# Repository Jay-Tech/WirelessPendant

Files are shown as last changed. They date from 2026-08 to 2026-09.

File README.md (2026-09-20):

# Wireless Pendant

Firmware for a wireless handwheel pendant for a grblHAL machine, and for the
receiver board that carries it to the PC. The sender application it talks to is
a separate project — [Jay-Tech/GrblHAL-Sender](https://github.com/Jay-Tech/GrblHAL-Sender),
whose [Wireless Pendant](https://github.com/Jay-Tech/GrblHAL-Sender#wireless-pendant)
section covers the settings at that end. What crosses between them is
[the wire protocol](micropython/pendant/protocol.py) — newline-delimited JSON,
the same either way it travels.

Two boards, both **ESP32-S3**:

| | |
|---|---|
| **pendant** | the handheld — encoder wheel, touch screen, battery. Waveshare ESP32-S3-Touch-LCD-3.5 |
| **receiver** | plugs into the sender's PC, presents a serial port, talks ESP-NOW to the pendant |

The pendant reaches the sender two ways. Over **ESP-NOW** it talks to the
receiver board, which needs no network and no credentials — this is the one it
is built around, because an open-source pendant cannot require the builder to
have usable WiFi in their shop. Over **WiFi** it joins the shop network and
opens a TCP session to the sender directly; that path stays because it is the
reference every jog constant was fitted against.

New board? → [Setting up a board](#setting-up-a-board). One command.

## The hardware

Three things, and none of them is a breadboard any more: an all-in-one host
board, a passive PCB that breaks its header out, and a printed enclosure. All of
it lives under [`hardware/`](hardware/).

| | | |
|---|---|---|
| **host board** | bought | [Waveshare ESP32-S3-Touch-LCD-3.5](https://www.waveshare.com/esp32-s3-touch-lcd-3.5.htm?sku=30733) — MCU, display, touch, PMIC and radio on one board |
| **PSB v1.0** | [`hardware/PendantPcb/`](hardware/PendantPcb/) | breaks that board's 32-pin header out to the handwheel and the three buttons. Carries no components at all |
| **enclosure** | [`hardware/CADandSTL/`](hardware/CADandSTL/) | Fusion 360 sources and printable STLs — the handheld, and a dock for it |

**The bill of materials is five orderable items, with no passives at all:** the
host board, an MPG handwheel, three tactile switches, a LiPo cell, and whatever
the printer eats. A 5 V boost module and the encoder's 22 kΩ divider pair were
both on that list until 2026-08-15 and were measured off it rather than reasoned
off it — [platform-decision.md](hardware/platform-decision.md) carries the
numbers, and [Encoder wiring](#encoder-wiring) below keeps the divider material
for the Pico build and for characterising an unknown wheel.

### The host board

[Waveshare ESP32-S3-Touch-LCD-3.5](https://www.waveshare.com/esp32-s3-touch-lcd-3.5.htm?sku=30733),
SKU 30733.

| | |
|---|---|
| MCU | ESP32-S3R8, dual Xtensa LX7 @ 240 MHz |
| Memory | 512 KB SRAM + **8 MB octal PSRAM**, 16 MB flash |
| Display | 3.5" IPS, 320 x 480, ST7796 over SPI |
| Touch | FT6336U, I²C `0x38`, polled |
| Power | **AXP2101** — charger, power path, fuel gauge and power button in one part, switching rather than linear |
| Battery | 3.7 V LiPo on an MX1.25 header, plus a separate SH1.0 header for an RTC cell |
| Radio | WiFi 4 (2.4 GHz) + BLE 5 on an onboard antenna, **with an IPEX pad for an external one** |
| Unused here | PCF85063 RTC, QMI8658 IMU, ES8311 codec, mic, speaker header, TF slot, camera header |
| Break-out | one 32-pin, 2.54 mm header — which is what PSB v1.0 mates to |

Two of those are why the board won. The **IPEX connector** — reached by
resoldering one resistor — is worth more on a handheld carried around a steel
machine than any latency figure measured here, and the Pico 2 W's antenna is
fixed. The **AXP2101** does in one part what the Pico build needed a LiPo Amigo
Pro and its wiring to do. The 8 MB PSRAM is enough for a full 320x480x2
framebuffer, which is also why the committed MicroPython build is the
`SPIRAM_OCT` variant rather than the plain one — see [ESP32-S3](#esp32-s3).

**The pin map is not in Waveshare's wiki and cannot be read off their schematic
PDF.** It came from their demo code, examples 08 and 11, which agree — and three
of the pins turn out not to be pins:

- **The LCD has no chip select.** The panel is permanently selected, so
  `st7796.py` has to tolerate `cs=None` rather than toggle something that does
  not exist.
- **LCD reset is an I²C write**, to a **TCA9554 expander at `0x20`** that is not
  in the board's advertised feature list and answers writes but not reads. The
  driver takes a reset *callable* instead of a pin, so the caller supplies either
  a pin toggle or an expander write and the driver stays portable.
- **Touch breaks out neither INT nor RST**, and needs neither, being polled.

Everything else transferred intact — the ST7796 init sequence, MADCTL, `INVON`,
the framebuffer push, and the whole of `screen.py` including the portrait layout,
the DRO digits, the step grid and the probe page. USB-C sits at the bottom edge,
which is where the reference pendant puts its cable, so the enclosure works with
it rather than against it.

An I²C scan of the board reads `0x18` ES8311, `0x20` TCA9554, `0x34` AXP2101,
`0x38` FT6336U, `0x51` PCF85063, `0x6b` QMI8658. That AXP2101 at `0x34` is also
how [`setup.py`](tools/setup.py) tells a pendant from a receiver, since the two
enumerate identically over USB — and it reads the chip ID rather than pinging the
address, so something else answering there is not mistaken for a battery.

> **The AXP2101's fuel gauge is not to be trusted on this board**, and the
> pendant does not use it. See [Battery and backlight](#battery-and-backlight)
> for what it did and what replaced it.

### PSB v1.0 — the breakout PCB

[`hardware/PendantPcb/`](hardware/PendantPcb/) is the KiCad project, with the fab
output in [`production/`](hardware/PendantPcb/production/).
[daughter-board.md](hardware/daughter-board.md) is the spec and the argument
behind it.

**It is built, and the pendant runs on it** — this is a board in service rather
than a drawing. The only difference between the fabricated boards and what is in
the repo is the silkscreen: they were made before the `PSB v1.0` version marking
was added, so they carry the functional labels and no revision. Nothing
electrical differs.

It exists because the host board brings almost everything out on that one
header, so a single mating board reaches every signal the pendant needs. The
alternative is seven flying leads soldered to a header, in a tool that gets
carried around a shop.

**Seven signals, and no components.** The move to a 3V3 encoder removed the last
two resistors it would have carried.

| Net | GPIO | J2 pin | Goes to |
|---|---|---|---|
| Encoder A | **9** | 14 | J3 pin 3 — direct, no resistor |
| Encoder B | **10** | 12 | J3 pin 4 — direct, no resistor |
| Encoder Vcc | — | 32 | J3 pin 1. **+3V3, measured 3.29 V — not 5 V, not VBAT** |
| Encoder 0V | — | 4, 30 | J3 pin 2 |
| `feed_hold` | **38** | 7 | SW1, silkscreened `HOLD` |
| `cycle_start` | **39** | 9 | SW2, silkscreened `START` |
| `zero_axis` | **40** | 11 | SW3, silkscreened `ZERO`, long hold |

The GPIO column was measured on the assembled handheld, 2026-08-16, and matches
`BUTTON_MAP` and `ENCODER_PIN_A/B` in
[`pendant.py`](micropython/pendant/pendant.py) — which is the authority. If
either moves, both have to. Buttons are active low against the S3's internal
pull-ups, with no external pull-ups and no debounce parts;
[`buttons.py`](micropython/pendant/buttons.py) debounces in software and has done
since the Pico build.

**Pin 32 is the one worth a meter.** The whole 3V3 encoder decision rests on it
being a regulated rail: the wheel is open-collector, so its outputs swing to
whatever supplies it, and they reach GP9 and GP10 with nothing in the way. On
VBAT or VBUS that is over the S3's ~3.6 V absolute maximum. 3.29 V says it is the
right rail.

**54.50 x 100.00 mm**, 2 mm chamfers on all four corners, and four drill groups —
which is the acceptance test, because anything outside the set is then visible at
a glance:

| Diameter | Plating | Count | |
|---|---|---|---|
| 0.300 | PTH | 2 | vias |
| 1.000 | PTH | 36 | 32 header + 4 encoder |
| 1.300 | PTH | 6 | three switches, two pads each |
| 2.200 | NPTH | 6 | mounting |

A missing 1.300 group means the switches were placed after the export — which
happened, and produced a zip with no buttons on it at all.

Two things on the board are deliberate traps, and both are cheap to check:

- **`+BATT` at J2 pin 1 is a single-node net** — that pad and nothing else on the
  board. Mate the boards and probe it: battery voltage means the numbering
  composes correctly through symbol, footprint and placement; 0 V or 3.3 V means
  one of those three mirrors did not cancel. Safe to probe precisely because
  nothing else is on it.
- **J3 has no keying**, and carries 3V3 and GND adjacent to each other. A cable
  fitted backwards puts reverse polarity across the wheel, so the `+ - A B`
  silkscreen and the pin 1 mark are load-bearing rather than decorative.

The three switches sit **19.0 mm apart, centred on the board's own centreline**.
The first layout had them at 19.5 and 18.5 with the middle one 0.5 mm off, and
unequal spacing between three caps is visible every time once the enclosure is
on.

A **reverse-polarity guard** for the battery is a second, smaller board. It shares
no net with PSB v1.0, which is why it is not on it, and
[daughter-board.md](hardware/daughter-board.md) has the circuit, what to buy, and
how to prove it before it meets the host board. Its KiCad project is gitignored,
so that specification is the only copy of it a clone gets.

### Printed parts

[`hardware/CADandSTL/`](hardware/CADandSTL/). Each folder holds one Fusion 360
file and the STLs exported from it — the `.f3d` is the source and the thing to
edit, the STLs are what a slicer wants. Sizes below are each mesh's measured
bounding box.

**The handheld** — [`Pendant/`](hardware/CADandSTL/Pendant/), from `Pendant.f3d`:

| File | Size, mm | |
|---|---|---|
| `Pendant.stl` | 70.00 x 27.65 x 186.00 | the body |
| `PcbCover.stl` | 54.70 x 3.16 x 100.00 | closes over PSB v1.0 — the footprint is that board's 54.50 x 100.00 plus clearance |
| `BatteryCover.stl` | 65.60 x 8.50 x 75.16 | the cell bay |
| `Button1.stl` | 10.80 x 10.64 x 8.80 | a cap for one of the three switches |
| `Button3.stl` | 10.80 x 10.64 x 8.80 | same envelope, different geometry |
| `ButtonUsbV2.stl` | 13.00 x 10.54 x 8.80 | the wider cap |
| `PowerButton.stl` | 8.39 x 3.60 x 4.60 | reaches the AXP2101's power button through the shell |

**The dock** — [`Mount/`](hardware/CADandSTL/Mount/), from `Mount.f3d`:

| File | Size, mm | |
|---|---|---|
| `Mount.stl` | 82.00 x 37.09 x 102.00 | the cradle the pendant sits in |
| `MountBase.stl` | 82.00 x 37.09 x 10.00 | its base, same footprint |
| `MountUsb.stl` | 20.00 x 20.00 x 5.90 | carries the USB-C end |
| `MountUsbLock.stl` | 11.70 x 6.10 x 17.70 | retains it |

**The body is 186 mm in its longest axis**, so it wants a bed with at least that
much in one direction — a 220 mm printer is fine, a 180 mm one is not.

**The button caps are one dimension chain, not three independent choices.** The
header fixes PSB v1.0's position relative to the host board in all three axes,
and the caps have to reach the enclosure top from there — so board stack height,
switch height and cap height are a single sum. The requirement the caps are cut
against is that each one **bottoms on the enclosure** at the end of its stroke
rather than on the switch, so the switch never takes the force of a gloved thumb,
and that the plunger is guided by a bore in the shell rather than by a spacer
resting on the board. [daughter-board.md](hardware/daughter-board.md) has the
reasoning; `Pendant.f3d` is where to check it.

## Why there is a Pico in here

The project started on a Raspberry Pi Pico 2 W, and that board is still on the
bench as `pico` — it is the reference the ESP32 gets compared against when
something feels wrong, which is why the notes below are kept rather than
deleted. Nothing shipping runs on it.

## Pico 2 W board notes

| | |
|---|---|
| MCU | RP2350, dual Cortex-M33 @ 150 MHz **or** dual Hazard3 RISC-V |
| RAM / flash | 520 KB SRAM / 4 MB QSPI |
| PIO | 3 blocks, 12 state machines |
| Radio | WiFi 4 (802.11n, 2.4 GHz) + Bluetooth 5.2 |
| Power | 1.8-5.5 V into VSYS via onboard buck-boost |

Three things that bite people on this specific board:

- **The onboard LED is not a GPIO.** It hangs off the CYW43 radio chip, so it's
  `Pin("LED")`, never `Pin(25)`. Most Pico tutorials assume a non-W board and
  will silently do nothing.
- **GP29 belongs to the WiFi SPI**, so the usable ADC channels are GP26/27/28
  (channels 0-2). Channel 4 is the internal temperature sensor.
- **Erratum RP2350-E9.** On the A2 stepping, an input pin can latch near 2.15 V
  instead of reading low, and the internal pull-downs are too weak to fix it.
  This hits PIO input programs too. Use an external pull-down of 8.2 kΩ or
  smaller. Stepping A4 corrects it — worth checking which one your board has
  before you spend an evening debugging a "broken" input.

## Setting up a board

```bash
python tools/setup.py
```

One command from a blank ESP32-S3 to a working pendant or receiver. It asks
what you are setting up, finds the board, flashes MicroPython if the board
needs it, checks the hardware matches the role, collects the WiFi and transport
settings, installs, restarts the board and reads back what it says on the way
up.

```bash
python tools/setup.py --pendant     # the handheld
python tools/setup.py --receiver    # the board at the sender's PC
python tools/setup.py --list        # what is attached, and what each one is
```

It replaces the two steps that used to be source edits: `BOARDS` in
[`tools/board.py`](tools/board.py) and a hand-filled `secrets.py`. **If you are
building this for the first time, this is the only thing you need to run** —
everything below is the manual equivalent, kept because it is what to fall back
on when a step misbehaves.

Two things worth knowing about how it finds boards:

- **It never opens a device it has not identified.** Only two USB descriptors
  are eligible — MicroPython on an S3 and on a Pico. Everything else is listed
  and skipped, and a grblHAL controller is named in that listing so you can see
  it was seen and left alone. This matters more than it sounds: `mpremote
  connect auto` once grabbed the STM32 controller on this bench and sent it
  raw-REPL bytes with a machine powered.
- **Each board records what it is**, in a `device.json` written at setup. That
  is what lets a board be found without an entry in `BOARDS`, and it is what
  `sync_board.py --receiver` now checks before it will write `receiver.py` over
  a `main.py` — the pendant and the receiver are both ESP32-S3 and enumerate
  identically, so before this the only guard was a name in a table that a new
  build had not filled in yet.

A pendant board is told apart from a receiver by the **AXP2101 power chip** at
I²C `0x34`, which the pendant carries and a bare receiver does not — and the
chip ID is read rather than the address pinged, so something else answering at
that address is not mistaken for a battery.

Set the receiver up on the sender's PC and it will offer to write the port into
the sender's own config. The sender still never scans for that port itself,
deliberately — see `PendantConfig` for why. This is not scanning; it just
flashed the board and knows where it is.

## Flashing MicroPython

The manual path, and the reference for what `setup.py` does.

### Pico 2 W

1. Download the Pico 2 W `.uf2` from
   [micropython.org/download/RPI_PICO2_W](https://micropython.org/download/RPI_PICO2_W/)
   — take whatever is current there rather than matching the S3 build committed
   at the root, since the two ports version independently. Make sure it's the
   `RPI_PICO2_W` build —
   the plain `RPI_PICO2` build has no WiFi and the plain `RPI_PICO_W` build is
   for the older RP2040 board.
2. Hold **BOOTSEL** while plugging in USB. The board mounts as a drive named
   `RP2350`.
3. Copy the `.uf2` onto it. The board reboots into MicroPython automatically.

If the board misbehaves after switching between Arm and RISC-V builds, or
between MicroPython and C SDK firmware, flash `flash_nuke.uf2` first to wipe
the flash, then reflash. Leftover filesystem blocks confuse the new firmware.

### ESP32-S3

Both the pendant and the receiver are ESP32-S3s, and neither takes a `.uf2` —
there is no BOOTSEL drive to drag a file onto, so flashing goes over the serial
port with `esptool`. The build this repo runs is committed at the root, and it
is the **`SPIRAM_OCT`** variant — these boards have octal SPIRAM, and the plain
`ESP32_GENERIC_S3` build leaves it unused. That mismatch does not fail at the
flash or at the boot; it surfaces much later as an allocation running out while
the pendant paints its display, which reads as a screen bug.

`setup.py` picks that variant on its own when both are sitting at the root, and
asks when it genuinely cannot tell — two versions of the same variant, say,
which is what a version bump leaves behind.

```bash
python -m pip install esptool
```

Put the board into its ROM bootloader: hold **BOOT**, tap **RESET**, release
**BOOT**. It re-enumerates as `303a:1001`, which `tools/board.py` labels
*"ROM bootloader — esptool, not mpremote"*. In MicroPython it is `303a:4001`
instead, and `esptool` will not talk to that one.

Then find the port it came up on — and look it up again rather than reusing what
it had a moment ago. The bootloader and MicroPython present different USB
descriptors, so Windows renumbers the board every time it is flashed. That is
also why every tool here targets a serial number instead of a COM port.

```bash
python -m esptool --chip esp32s3 --port COM# erase-flash
```

```bash
python -m esptool --chip esp32s3 --port COM# --baud 460800 write-flash -z 0 ESP32_GENERIC_S3-SPIRAM_OCT-<version>.bin
```

Offset `0`, not the `0x1000` the original ESP32 takes.

esptool 5 renamed these from `erase_flash` and `write_flash`; the underscore
forms still run but print a deprecation warning, which in the middle of a flash
reads like a fault. `setup.py` picks the spelling from the installed version.

Reset the board and it comes up in MicroPython with a new serial number. Every
S3 here enumerates identically, so that serial number is what distinguishes a
pendant from a receiver, and every tool resolves through it rather than through a
COM port.

There are two places it can come from. `setup.py` writes a `device.json` **on the
board**, which is what lets a board be recognised with no entry in any table —
prefer that. `BOARDS` in [`tools/board.py`](tools/board.py) is the older path and
still works; every id in it is this bench's, so all of them are wrong for you.
`python tools/board.py` lists what is attached and says so when the configured
board is not among them.

## Running the smoke test

Uses [`mpremote`](https://docs.micropython.org/en/latest/reference/mpremote.html):

```bash
pip install mpremote
```

Commands below invoke it as `python -m mpremote` rather than the bare
`mpremote`. On Windows with Microsoft Store Python, the `Scripts\` directory
holding `mpremote.exe` is not on `PATH`, so the bare command fails with
*"not recognized as the name of a cmdlet"* even though the install succeeded.
The `-m` form sidesteps that and works on every platform. See
[PATH fix](#windows-store-python-path) if you want the short command back.

> ### ⚠️ Do not use `connect auto` on a machine with a CNC controller attached
>
> `auto` connects to the first USB serial device it finds. If a grblHAL
> controller is plugged in, that can be the controller rather than the Pico —
> and mpremote will then send raw-REPL control bytes (`Ctrl-A`/`Ctrl-C`) to
> your machine controller trying to get a Python prompt. It happened here: the
> STM32 board on `0483:5740` got grabbed instead of the Pico and reset.
>
> Target the board explicitly by its unique ID instead. The ID is held in one
> place, [`tools/board.py`](tools/board.py), and every tool resolves through it
> — so there is no serial number to copy from a docstring and mistype. It stays
> correct across COM port renumbering.
>
> Run it to see what is attached and which device is the target. It labels the
> controller so it cannot be picked by accident:
>
> ```bash
> python tools/board.py
> ```
>
> Override it without editing anything by setting `PICO_DEVICE`.
>
> Pico boards report a `2e8a:` vendor ID (`0005` = MicroPython running,
> `000f` = RP2350 BOOTSEL). An STM32 grblHAL board reports `0483:5740`. Use
> the serial number in the second column as `id:<serial>`.

Set up credentials (this file is gitignored — it never reaches a commit):

```bash
cp micropython/secrets.example.py micropython/secrets.py
```

**Edit it before running anything.** Leaving the placeholder SSID in place
makes `wifi_join` fail with `no such network in range`. Then copy it to the
board and run the test:

```bash
python tools/sync_board.py
```

```bash
python tools/on_board.py micropython/smoke_test.py
```

`run` streams the script from your PC rather than installing it, but imports
still resolve on the board — which is why `secrets.py` has to be copied over
first. To drop into the REPL instead:

```bash
python -m mpremote connect $PICO_DEVICE repl
```

To confirm the board is seen at all, and check what it's running:

```bash
python -m mpremote devs
```

A Pico 2 W shows a `2e8a:` vendor ID. PID `0005` means MicroPython is already
flashed and talking; PID `000f` means the board is sitting in RP2350 BOOTSEL
mode waiting for a UF2.

Prefer a GUI? [Thonny](https://thonny.org/) works well: set the interpreter to
*MicroPython (Raspberry Pi Pico)* and it handles the board filesystem for you.

### What it checks

Six stages, each reporting PASS / FAIL / SKIP with a summary at the end:

| Stage | Proves |
|---|---|
| `identity` | firmware, chip ID, clock, heap, filesystem |
| `led` | GPIO path via the CYW43 — visible blink |
| `temp` | ADC works (internal sensor, uncalibrated, ±a few °C) |
| `wifi_scan` | radio powers up and hears networks |
| `wifi_join` | association + DHCP lease |
| `net_io` | DNS + TCP + HTTP, end to end |

The last three need `secrets.py`; without it they report SKIP and the rest
still runs, so the script is useful before you've picked a network.

Two of those stages are Pico-shaped: `led` goes through the CYW43 radio chip
rather than a GPIO, and `temp` reads the RP2350's internal sensor. Both are
board-level proof of life rather than anything the pendant depends on — on an S3
the equivalent bring-up is
[`selftest_board.py`](micropython/pendant/selftest_board.py) and the per-subsystem
self-tests under [Pendant hardware summary](#pendant-hardware-summary).

## Pendant hardware summary

Every pin the pendant uses, in one place — the part you want with a soldering
iron in your hand. Why each one is where it is: [The hardware](#the-hardware)
above, and the design notes below.

**Discrete parts: none.** Nothing sits between the host board and the
peripherals — no level shifters, no pull-ups, no dividers, no transistors. The
encoder's 22 kΩ pair left with the move to 3V3, and the display and touch panel
are on the host board rather than wired to it.

| GPIO | Net | Notes |
|---|---|---|
| GP9 | encoder A | direct, no resistor |
| GP10 | encoder B | direct, no resistor |
| GP38 | feed hold | to GND, internal pull-up |
| GP39 | cycle start | to GND, internal pull-up |
| GP40 | zero axis | to GND, internal pull-up, long hold |
| GP1 / GP2 / GP5 | LCD MOSI / MISO / SCK | SPI2, all on the host board |
| GP3 | LCD DC | |
| GP6 | LCD backlight | PWM — see [Battery and backlight](#battery-and-backlight) |
| — | LCD CS | there isn't one; the panel is permanently selected |
| — | LCD RST | TCA9554 at `0x20`, pin 1 |
| GP8 / GP7 | I²C SDA / SCL | I2C0 — touch, PMIC, RTC and IMU all share it |
| **3V3** | encoder Vcc | **not 5 V, not VBAT.** J2 pin 32, measured 3.29 V |
| GND | encoder 0V | J2 pins 4 and 30 |

Deliberately unconnected on PSB v1.0: **J2 pin 2 (VBUS)**, which measures 0 V
without USB and 4.89 V with, and **J2 pin 31 (3V3)**, a second tap on the rail
that pin 32 already supplies.

Axis and step selection live on the touch panel rather than on buttons. Both are
bigger targets than a button and, unlike a button, say what is selected without
being read back off a status line. What stays physical is what has to work
without looking and while a job is running — feed hold and cycle start are the
only pendant commands the sender will forward mid-job, and zeroing is a long
hold because it rewrites the work offset.

> **The Pico 2 W map differs in almost every position**, and is kept because that
> board is still the bench reference. Encoder A/B on **GP2/GP3** through the
> 22 kΩ dividers; buttons on **GP7/GP8/GP9**; touch on I2C1 — SDA **GP10**, SCL
> **GP11**, with INT **GP12** and RST **GP13**; display on SPI0 — SCK **GP18**,
> MOSI **GP19**, DC **GP20**, RST **GP21**, CS **GP17**, backlight **GP22**.
> There the encoder *and* the display both run from **VBUS at 5 V**, which is the
> substantive difference: on the S3 the encoder is on the regulated 3V3 and the
> display is not wired at all. [`pendant.py`](micropython/pendant/pendant.py)
> carries both maps and picks on the port, so nothing above the pin constants
> knows which board it got.

**Bringing a rebuilt harness up**, one layer at a time rather than all at once:

```bash
python tools/on_board.py micropython/pendant/probe_encoder.py      # characterise A/B
python tools/on_board.py micropython/pendant/selftest_pcnt.py      # the S3 decoder
python tools/on_board.py micropython/pendant/selftest_quadrature.py # the Pico decoder
python tools/on_board.py micropython/pendant/selftest_st7796.py    # backlight, then pixels
python tools/on_board.py micropython/pendant/selftest_touch.py     # bus, then part, then touches
python tools/on_board.py micropython/pendant/selftest_link.py
```

Each separates the failures the one above it would otherwise mask. The decoder
self-test is per-port: the S3 counts in PCNT hardware, the Pico uses a hard pin
IRQ, and `pendant.py` chooses between them — a soft IRQ on the ESP32 would sit
behind the interpreter where a display refresh could hold it off long enough to
drop edges.

## Design notes

> **Quietening the pendant for machine work.** Set `TRACE_DUMP_BUDGET = 0` in
> [`micropython/pendant/jog.py`](micropython/pendant/jog.py) to stop the trace
> tables. Everything is still counted and still reported in the periodic
> one-liner, so nothing is lost but the tables.
>
> It matters because printing can block. With no USB host attached MicroPython
> discards console output, so a pendant running standalone from `main.py`
> cannot stall on it however much it writes — but attached to `mpremote`, a
> host that is not draining fast enough blocks `print()`, and a blocked print
> blocks the whole event loop: the socket read and the jog scheduler with it.
> A run with seventy trace dumps stalled the loop for a full second.

A handheld MPG pendant — handwheel, buttons, display — that talks to the
**sender application**, not to the controller:

```
  pendant  --ESP-NOW-->  receiver (USB serial)  --\
                                                   >-- Sender (PC) --> controller
  pendant  --WiFi/TCP------------------------------/
```

Either transport carries the same newline-delimited JSON, so nothing above the
transport — jogging, buttons, the status feed — knows which one a pendant
arrived on.

### Why not straight to the controller

The obvious design — pendant connects directly to the machine over the network —
does not work, for two independent reasons:

- **grblHAL's telnet server accepts exactly one client.** `telnetd.c` refuses a
  second connection outright (`if(session->pcb) return ERR_CONN;`). The sender
  already holds that session, so the pendant cannot have one.
- **On an SLB, the board isn't reachable anyway.** Sienci documents a direct
  PC-to-board Ethernet cable on a static `192.168.5.x` subnet. That link is an
  isolated segment with no route from the WiFi network.

Going through the sender avoids both, works with any controller, and keeps the
sender as the single arbiter of the command queue — which is what GRBL requires
regardless of transport.

### Encoder wiring

> **The RP2350 is not 5 V tolerant.** A 5 V handwheel will damage a GPIO if
> wired straight in. Identify the output type first.

Count the terminals:

| Terminals | Type | Wiring |
|---|---|---|
| **6** — A, B, 0V, Vcc, A-, B- | Differential **line driver**, push-pull, swings a full 0–5 V | Divider on A and B (below), or an RS-422 receiver |
| 4 — A, B, 0V, Vcc | Single-ended; still need to know which kind | Open-collector: 4.7 kΩ pull-up to **3.3 V**. Push-pull: divider as below |

**Six terminals does not automatically mean a line driver.** The wheel used
here has A, B, 0V, Vcc, A-, B- and turned out to be **open-collector with an
internal pull-up**, measured at ~13.3 kΩ. Characterise before wiring:

```bash
python tools/on_board.py micropython/pendant/probe_encoder.py
```

An open-collector output already has a pull-up forming the top leg of a
divider, so adding an external series resistor only drops the level further.
One resistor to ground is the whole circuit:

```
  encoder A ──┬────────────────> GP2
             [22k]
              │
             GND                 (same again for B -> GP3)

  encoder 0V  ──────────────────> GND  (pin 38)
  encoder Vcc ──────────────────> VBUS (pin 40, USB 5 V)
```

4.909 V × 22/(13.3+22) = **3.06 V**. The level has to clear the RP2350's
input-high threshold (~2.15 V) without passing its absolute maximum of
**IOVDD + 0.3 V = 3.6 V**.

| To ground | Level | |
|---|---|---|
| 10k | 2.11 V | fails — below input-high |
| 20k | 2.95 V | works |
| **22k** | **3.06 V** | best centred, tolerant of pull-up variation |

> **Superseded on the ESP32-S3 build, 2026-08-15.** The encoder now runs from
> the regulated 3V3 with **no resistors at all** - simpler, and a better logic
> level than the divider above. The paragraph that used to sit here said
> powering it at 3V3 "is not worth it: the part is specified at 5 V and an
> under-driven encoder that works intermittently is the worst outcome
> available." That was wrong, and is left visible because it failed in an
> instructive way.
>
> It conflated the supply with the interface. The wheel is **open-collector**,
> so its output level is its own supply: at 3V3 the pin sees a clean 3.3 V,
> where the divider above delivers **3.06 V**. The arrangement being defended
> was the more under-driven of the two. The only real question was whether the
> wheel's internals run at 3.3 V, and they do - 16,695 counts at up to 195
> detents/s with nothing dropped.
>
> Two things still matter. **Remove the resistors when you move to 3V3, not
> after**: kept, they divide against the internal pull-up and give ~2.06 V,
> under the input-high threshold on both parts. And **do not take Vcc from the
> battery rail** - the level follows the supply, so it passes the S3's ~3.6 V
> absolute maximum on a charged cell and sags as it drains.
>
> See [hardware/platform-decision.md](hardware/platform-decision.md). The
> divider material above stays for the Pico 2 W build and for characterising an
> unknown wheel.

A- and B- go unused. They exist for noise immunity over a long cable; if
`errors` starts climbing because the lead runs near a VFD or steppers, feed
A/A- and B/B- into a 3.3 V RS-422 receiver (MAX3095 or similar) and take
single-ended 3.3 V out. Not needed for a short bench lead, and PSB v1.0's
4-pin J3 does not land them.

Erratum E9 is not a factor either way here, since the input is actively driven
rather than resting on a weak pull-down.

Defaults are **GP2 = A, GP3 = B** on the Pico and **GP9 = A, GP10 = B** on the
ESP32-S3.

**Check before connecting:** power the encoder from 5 V and GND only, and
measure A against 0V while turning slowly. It should swing hard between ~0 V
and ~5 V. If it never reaches 5 V unaided it is open-collector, not a line
driver, and wants pull-ups instead of dividers.

### Battery and backlight

Both are ESP32-S3 only - they depend on the AXP2101 the board carries.

**Charge is read from the cell voltage, not from the PMIC's fuel gauge.** The
gauge on this board is wrong: at a steady 4.01 V on charge it reported 81%,
then decayed 82% to 59% over thirty seconds, then read 31%. A cell at 4.0 V is
genuinely 75-85%. It reads 0 correctly with no cell, so it is not dead - it is
worse than dead, because every individual reading looks plausible and nothing
about the number says it is wrong.

[`battery_monitor.py`](micropython/pendant/battery_monitor.py) interpolates a
LiPo curve instead. A curve is the cruder instrument and its limits are worth
knowing: it reads high while charging, dips during radio bursts as the cell
sags under load, and is nearly flat between 3.7 and 3.9 V where a few millivolts
move it ten points. It is honest at the ends, which is where a warning has to
be right. The gauge is still logged beside it at boot, so a board where they
agree will say so.

The panel shows it on the link row: grey above 20%, amber to 10%, red below,
and green whenever charging at any level. `--` rather than `0%` when there is
nothing trustworthy to say - no cell, no PMIC, or a reading outside the curve -
because a confident zero reads as flat rather than as unknown.

**The backlight dims to 15% after two minutes idle**, which is most of what the
pendant can do about its own battery: the backlight draws 100-150 mA against
50-120 mA for the CPU and radio together. Dim rather than off, because a dim DRO
can still be read from the machine and a blank one has to be woken before it can
answer the glance that prompted it. Only operator input counts as use - wheel,
touch, buttons - deliberately not machine motion, since a job can run for an
hour with nobody touching the pendant and that is exactly when it is worth
turning down.

```bash
python tools/on_board.py micropython/pendant/selftest_battery.py    # cell to panel
python tools/on_board.py micropython/pendant/selftest_backlight.py  # PWM or on/off
python tools/on_board.py micropython/pendant/probe_axp2101.py       # does a reading hold still
python tools/on_board.py micropython/pendant/probe_axp2101_map.py   # dump, for diffing
python tools/test_battery.py                                        # the curve, no board
```

`selftest_backlight.py` earns its place: the driver falls back to on/off where a
port has no PWM, and that fallback silently turns "dim after two minutes" into
"blank after two minutes". It says which one you actually got.

**Probes here take no input mid-run.** Driven through `mpremote`, output does
not reach you until the run has finished, so a prompt printed during one is read
after it is over. Anything needing hardware moved compares two separate runs
instead - dump, change the thing, dump again, diff. `probe_axp2101_map.py` is
built that way; three earlier attempts at a timed window were lost before that
was understood, and each reported "nothing moved", which is exactly what a real
negative result looks like.

### Network link

[`link.py`](micropython/pendant/link.py) joins WiFi and holds a TCP session to
the sender, reconnecting on its own. The pendant is the client: the sender is
a fixed always-on machine, the pendant is the thing that wanders off and gets
switched off.

Three things it handles that a plain socket does not:

- **Silent death.** A session whose peer vanished — PC asleep, AP dropped —
  stays open for minutes before the stack notices, which on a pendant reads as
  a handwheel that has simply stopped working. A ping every 3 s plus a 10 s
  receive deadline turns that into a fast, visible reconnect.
- **Backpressure.** The send queue is bounded and drops oldest. A pendant that
  can't reach the sender must never build a backlog of stale jog commands that
  all execute at once when the link returns.
- **Flush before close.** Closing a socket discards whatever is still queued,
  so `flush()` exists and any orderly shutdown must call it. Skipping it loses
  the last few messages silently, after they have already been counted as sent.

### ESP-NOW receiver

The other transport, and the one the pendant is moving to. Instead of joining
the shop WiFi it talks ESP-NOW straight to a second ESP32-S3 plugged into the
sender's PC, which presents a serial port. What crosses that port is exactly
what crossed the TCP socket — the same newline-delimited JSON — so the sender
reads a different transport and the protocol itself does not change.

[`micropython/receiver/receiver.py`](micropython/receiver/receiver.py) is the
whole of it, and it is one file with no dependencies: it imports only `sys`,
`select`, `time`, `network` and `espnow`, all built into the ESP32 port. No
`secrets.py` either, since ESP-NOW needs no credentials.

Setting up the receiver is one command, which also does the flashing:

```bash
python tools/setup.py --receiver
```

The manual equivalent, after flashing MicroPython above:

1. See what is attached, and note the board's serial number:

```bash
python tools/board.py
```

2. Set `receiver` in `BOARDS` in [`tools/board.py`](tools/board.py) to that
   `id:`.
3. Install it:

```bash
python tools/sync_board.py --receiver
```

4. Reset or replug the board.

Step 4 is easy to skip and looks like a failure when you do. `mpremote` leaves
the board in the REPL, so `main.py` is installed but not yet running — set one
up in place, look at the port, and a silent port reads as a bad install. Moving
the board to the shop PC resets it anyway, so this only bites when bench-testing
where you flashed it.

Step 3 copies `receiver.py` as `main.py` and nothing else, so the board comes up
on its own when the shop PC powers on, which is the whole point of it. Unlike
the pendant's `--main` there is no opt-in, because there is no development mode
to protect here.

It targets the board named `receiver` and ignores `PICO_DEVICE`. If you keep
more than one — a spare, or a bench board — name the others `receiver2`,
`receiver3` and select them with `--device receiver2`. The prefix is
load-bearing rather than descriptive: this refuses to run against a board whose
name does not begin `receiver`. Every S3 enumerates identically, so that name is
the only guard against writing the receiver's entry point over the pendant's — a
mistake that is silent at the time and shows up later as a pendant that does
nothing.

To watch it run without installing it:

```bash
python tools/on_board.py micropython/receiver/receiver.py --device receiver2 --no-sync
```

`--no-sync` matters: without it `on_board.py` copies the pendant's modules
first, which the receiver neither imports nor needs.

Pairing takes no configuration. The pendant broadcasts until something answers;
the receiver learns its MAC from the first packet and unicasts back. A pendant
that reboots keeps its MAC, so the receiver also answers a familiar peer that
has gone quiet — without that it would ignore the rebooted pendant's broadcasts
and never re-pair.

The receiver writes its own diagnostics into the same stream as
`{"t":"rx_note","msg":...}` rather than as bare prints, which would land
mid-protocol and read as a malformed line. The sender shows them as
`[Pendant] Receiver: …`. On power-up you should see:

```
{"t":"rx_note","msg":"receiver up, this board is 68:EE:8F:50:B2:84"}
```

and the pendant's MAC when one pairs. Those two lines are what to look at when
pairing is not working.

Only one thing may hold the port. The sender, `mpremote` and
[`tools/espnow_bridge.py`](tools/espnow_bridge.py) all open it exclusively, so
`sync_board.py` reporting *"could not read the board"* usually means the sender
is running. The bridge is retired now that the sender reads the port itself, and
must not be left running alongside it.

### Mock sender

[`tools/mock_sender.py`](tools/mock_sender.py) stands in for the real sender:
it accepts a pendant, applies incoming jogs to a simulated DRO, and streams
status back at 10 Hz. Turn the handwheel and the position moves.

```bash
python tools/mock_sender.py --verbose
```

Then, with `SENDER_HOST` set in `secrets.py`:

```bash
python tools/on_board.py micropython/pendant/selftest_link.py
```

The self-test drives synthetic handwheel motion — an out-and-back sweep on X, a
one-way Z move, buttons — and checks the DRO the sender reports back actually
follows. It needs no encoder or display wired.

### Running it

```bash
python tools/run_pendant.py
```

Syncs the board then starts the pendant. Both steps in one because forgetting
either is silent and misleading: no sync runs stale modules, and no run looks
exactly like a pendant that is broken rather than one that was never started.

`run_pendant.py` syncs the modules but not the entry point, so a board driven
this way still boots to a free REPL. Installing `pendant.py` as `main.py` is a
separate, deliberate step — `sync_board.py --main` does it, and
[`setup.py`](tools/setup.py) passes that flag for you, so **a pendant brought up
by `setup.py` does run at power-up**, which is the point of a pendant.

`main.py` is kept out of the sync's module list on purpose: otherwise every
development run would also change what the board does when it is next switched
on. The cost is that a board can sit with every module current and an entry point
months old — which happened, and ran for weeks with a `main.py` from before the
battery work while `axp2101.py`, `battery_monitor.py` and `screen.py` were all up
to date beside it. The panel showed `--` for charge, so it read as a hardware
fault rather than a stale file. `sync_board.py` now hash-checks the installed
entry point against `pendant.py` even when it is not installing it, and says when
the two differ.

The other cost is the REPL: `main.py` holds it from boot, so recovering a board
that fails inside the pendant means catching the gap before the script starts, or
reflashing. An escape hatch — skip startup if a button is held — is still worth
having and does not exist yet.

### Jog behaviour — open question

Two philosophies, and which feels right is a question for a real machine:

- **Velocity-follow** (current default). Stopping the wheel flushes queued
  motion and halts. The machine never runs on past your hand. Ten fast clicks
  may travel less than ten steps' worth, because the remainder is cancelled.
- **Queue-and-execute.** Every detent is honoured exactly, so ten clicks is
  always ten steps. The machine lags a fast spin and keeps moving after you
  stop.

Velocity-follow is the default because a handwheel is used to position by eye —
if you want an exact distance you would type it. Step size (the two step
buttons) is the coarse/fine control, which may well cover the "spin fast for
rough distance, crawl for fine" need without a second mode.

Compare them on a running pendant without reflashing:

```python
scheduler.cancel_on_stop = False   # queue-and-execute
scheduler.cancel_on_stop = True    # velocity-follow
```

The cancel threshold is `IDLE_MS_BEFORE_CANCEL`, 300 ms. It has to clear a slow
turn: someone winding continuously still produces a detent every few hundred
ms, and a shorter threshold fires between individual detents and truncates jogs
mid-move.

### Verifying the decoder

Decode logic runs on a PC with no board attached — it stubs `machine` and
drives the real class, so the test can't drift from the code:

```bash
python tools/test_quadrature.py
```

The hardware path (pin config, hard IRQ dispatch, speed headroom) needs two
jumpers, GP16→GP2 and GP17→GP3, which synthesise quadrature and read it back:

```bash
python tools/on_board.py micropython/pendant/selftest_quadrature.py
```

It reports where edges start getting missed. A hand-turned 100 PPR wheel peaks
around 2000 edges/s, so there should be a lot of margin above it.

## Windows Store Python PATH

Optional — only if you want to type `mpremote` instead of `python -m mpremote`.

Microsoft Store Python installs console scripts into a sandboxed per-user
directory that the Store's PATH shim doesn't cover. Find it with:

```bash
python -c "import sysconfig; print(sysconfig.get_path('scripts', 'nt_user'))"
```

Then append that one directory to your **user** PATH (this reads and writes
only the user scope, so it can't clobber the machine PATH):

```powershell
$s = python -c "import sysconfig; print(sysconfig.get_path('scripts','nt_user'))"; [Environment]::SetEnvironmentVariable('Path', [Environment]::GetEnvironmentVariable('Path','User') + ';' + $s, 'User')
```

Restart the terminal afterwards. Existing sessions keep the old PATH.

## Layout

```
micropython/
  pendant/              everything the handheld runs
    pendant.py            the program; installed as main.py
    jog.py                detents -> motion. The hard-won one; see the warning below
    protocol.py           the wire format, shared with the sender
    link.py               WiFi transport - joins, holds a TCP session, reconnects
    espnow_link.py        ESP-NOW transport - broadcasts until a receiver answers
    screen.py touch.py    UI, on ili9341.py / st7796.py / tca9554.py
    quadrature*.py        encoder decoding, PIO and PCNT variants
    axp2101.py            power chip: battery voltage and charge state
    battery_monitor.py    what the screen shows, off the above
    selftest_*.py         one per subsystem, streamed with on_board.py
  receiver/
    receiver.py           the whole receiver; installed as main.py
  secrets.example.py    template -> secrets.py, or let setup.py write it
  smoke_test.py         staged board bring-up check

tools/                  run from the repo root, never on the board
  setup.py              blank board -> working pendant or receiver
  board.py              which board is which, and what is safe to talk to
  sync_board.py         copy modules to a board, hash-compared
  on_board.py           stream a script to a board and watch it run
  mock_sender.py        stands in for the sender: accepts a pendant, moves a DRO
  replay_pendant.py     re-run a captured session against the jog logic
  test_*.py             host-side tests, no board needed

hardware/
  platform-decision.md  why this board and this link, with the measurements
  daughter-board.md     PSB v1.0: every net, the header mapping, as-built numbers
  carrier-board.md      the superseded Pico carrier, kept for its mechanical work
  PendantPcb/           KiCad for PSB v1.0; production/ is the fab output
  CADandSTL/
    Pendant/              body, covers and button caps - Pendant.f3d plus STLs
    Mount/                the dock - Mount.f3d plus STLs
  Outline.dxf Holes.dxf  board geometry out of Fusion, for KiCad to import
```

**Two hardware directories exist on the bench but not in a clone.** `.gitignore`
excludes the KiCad export (`hardware/PendantPcbExport`) and the reverse-polarity
guard's own project (`hardware/ReversePolarityPcb/PolarityProtector`), so neither
travels — the guard's specification in
[daughter-board.md](hardware/daughter-board.md) is the copy that does.

Credentials live in `secrets.py`, which is gitignored — `setup.py` writes it, or
copy `secrets.example.py` by hand. The example is tracked, so keep the
placeholders in it and never put real values there.

> **`jog.py` is not to be edited casually.** Its constants were fitted against
> a real machine over several sessions, and its comments record the attempts
> that failed. It also sits in series with a second rate regulator at the
> sender end, so a change here reacts to a change there. Read
> [Jog behaviour](#jog-behaviour--open-question) first.

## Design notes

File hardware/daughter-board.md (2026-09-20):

# Pendant daughter board

Breaks the ESP32-S3-Touch-LCD-3.5's 32-pin header out to the handwheel and the
three panel buttons. That is the whole job, and it carries no parts at all - the
3V3 encoder change removed the last two resistors.

A reverse-polarity guard for the battery is specified at the end of this
document. It was first proposed as part of this board but shares no net with it,
and belongs on its own small board at the host end - see that section.

It exists because the host board brings almost everything out on that one
header - the only other connectors are JST leads for the speaker, the RTC cell
and the battery, none of which the pendant uses through here. So a single
mating board reaches every signal the pendant needs, and the alternative is
seven flying leads soldered to a header, in a tool that gets carried around a
shop.

> **Status: built, and in use.** PSB v1.0 was fabricated and the pendant runs on
> it. The electrical side is settled, measured, and now proven in service.
>
> **One difference between the boards in hand and the current design:** they were
> made before the version marking was added to the silkscreen, so a physical board
> carries the functional labels but no `PSB v1.0` on it. Nothing electrical
> differs, and no respin is needed for it - the next batch picks it up.
>
> The enclosure it has to agree with is no longer being drawn in parallel; it is
> in [CADandSTL/](CADandSTL/) as `Pendant.f3d` and its STLs, with `PcbCover.stl`
> sized to this board.

## Every net on the board

Seven signals. Taken from `micropython/pendant/pendant.py`, which is the
authority - if this table and that file disagree, the file is right.

| Net | Host pin | Goes to | Note |
|---|---|---|---|
| Encoder A | GP9 | encoder connector | direct, no resistor |
| Encoder B | GP10 | encoder connector | direct, no resistor |
| Encoder Vcc | **3V3** | encoder connector | **not 5 V, not VBAT** |
| Encoder 0V | GND | encoder connector | |
| Feed hold | GP38 | button 1 | other side to GND |
| Cycle start | GP39 | button 2 | other side to GND |
| Zero axis | GP40 | button 3 | other side to GND, long hold |

Buttons are active low against the ESP32's internal pull-ups. No external
pull-ups, no debounce parts - `buttons.py` debounces in software and has been
doing so on real hardware since the Pico build.

**Confirm all five GPIOs are on the 32-pin header before laying out.** They
should be, since the bench harness reaches them today, but a signal that turns
out to live on a different connector is a respin, and it costs one minute with
a meter to rule out.

## Why the encoder is on 3V3, and why that matters here

Measured 2026-08-15. See [platform-decision.md](platform-decision.md) for the
full argument; the part that constrains this board:

- The handwheel is **open-collector with an internal pull-up**, so its output
  level is whatever its supply is. On 3V3 it presents a clean 3.3 V high
  straight to the GPIO.
- **No divider.** The 22 kOhm pair that the 5 V build needed is gone. Keeping
  it at 3V3 would give ~2.06 V, under the ESP32-S3's ~2.48 V input-high
  threshold, and would fail intermittently rather than outright.
- **Do not run the encoder from VBAT.** The level follows the supply, so a
  charged cell puts 4.2 V on a pin whose absolute maximum is ~3.6 V, and it
  sags as the cell drains. The regulated rail holds it still.

Evidence: 4,173 detents and 16,695 counts over thirty seconds at 100-195
detents/s with nothing dropped; low 0.12 V, high >= 3.22 V, duty 48/52 and
49/51.

**The 3V3 pin on the header carries the encoder's 20-40 mA** on top of whatever
the host board already draws through it. Almost certainly fine, but it is the
one current path on this board worth a glance at the host's trace before
committing.

## The header

The mating connector has to be taken from the part, not from vendor CAD or a
wiki page - pitch, row count, and pin 1 position. The display pin map for this
board came from Waveshare's demo code rather than their documentation, and a
header is the kind of thing that gets drawn optimistically.

**Make it impossible to mate rotated or offset.** A plain 2xN header will mate
180 degrees round, or one column out, and both put 3V3 somewhere it should not
be. Any one of these is enough:

- a shrouded, keyed header
- a standoff pattern that is deliberately asymmetric
- a mechanical feature on the enclosure that only allows one orientation

Silkscreen alone is not enough. It is on the side you cannot see once the
boards are stacked.

**Use several ground pins, not one.** The header will have more than one; tie
them all. It costs nothing and it is the difference between a ground return and
a ground wire.

## Buttons on the board, not on the panel

This reverses [carrier-board.md](carrier-board.md), which specified panel-mount
buttons because *"this is handled with gloves, with chips about, and a panel
button is the more robust part"*. That reasoning still stands on its own terms.
What changed is that putting them on the daughter board removes three pairs of
flying leads and a separate assembly step, and the robustness can be bought
back mechanically instead.

Two things decide whether it holds up:

**Side load is what kills tactile switches.** A gloved thumb pushes at an angle,
and a 6 mm tactile switch has almost no lateral tolerance. So the cap must be a
**plunger guided by a bore in the enclosure top**, not a spacer resting on the
switch. Then the case takes the side load and the switch only ever sees axial
force. This is the single most important mechanical detail on the board.

**The tolerance stack has to end in clearance, not crush.** Board seating height
through the header, plus switch height, plus cap, against the enclosure top.
Design the cap so it **bottoms on the enclosure** at the end of its stroke, with
the switch reaching its own click before that. A stack that ends the other way
holds three switches permanently pressed, which reads as a pendant that will not
stop asking for a feed hold.

Prefer a switch with a long travel and a firm, unambiguous click. Through a
glove and a printed cap, a short-travel switch gives no feedback at all, and the
operator presses it twice.

## Connectors

| For | Suggested | Why |
|---|---|---|
| Encoder | 4-pin JST-PH or XH | inside the enclosure, so latch and pitch matter more than height |
| Header | mirror the host board | measured from the part |

The handwheel's own cable decides the encoder connector as much as this board
does. If it arrives with flying leads, crimping them into a housing is kinder
to future disassembly than soldering them to the board - the wheel is the part
most likely to be swapped.

## Footprints to place and leave empty

They cost nothing unpopulated and each one saves a respin. Carried over from
[carrier-board.md](carrier-board.md), and the first is newly relevant because
the resistors it refers to were just removed by measurement:

- **22 kOhm pads on A and B to ground.** The 3V3 result is one wheel on one
  bench. A different handwheel, or a push-pull one, may want them back.
- **Pull-ups on A and B to 3V3**, in case a wheel turns out not to have an
  internal one.
- **Series-R and cap pads for an RC filter** on A and B.
- **ESD diodes on the encoder lines.** A handwheel cable in a shop with a
  concrete floor is a real path into a GPIO, and this is the board that path
  now runs through.

## Test points

Reachable pads on: 3V3, GND, encoder A, encoder B, and each button line. The
bring-up order below is only runnable with a meter if the nets are reachable,
and once the two boards are stacked almost nothing else is.

## What does not belong on this board

- **Anything at 5 V.** There is no 5 V anywhere in this design. The AXP2101's
  outputs all step down, and the boost that used to be in the BOM is gone.
- **The battery.** It reaches the host board's own JST connector, and nothing on
  this board draws from it or shares a net with it. The reverse-polarity guard
  specified below belongs on its own board at the host end, not here.
- **The power button.** It is on the host board and is now reached through the
  enclosure rather than wired to a header pin.

## The battery extension is the most dangerous part of the build

Not on this board, but it belongs with it because nothing else in the pendant
can destroy the host board on first power-up.

The cell reaches the host board's JST connector through an extension. **An
extension is exactly where polarity gets inverted**: a two-wire lead with a
housing on each end comes out straight or mirrored depending on which face the
contacts are crimped to, and the two look identical. Battery connector polarity
is not standardised between vendors.

**Meter the host board's pads against its silkscreen, and the cell, before the
first mating.** A reversed LiPo into the AXP2101's battery input is a dead board
and possibly a vented cell.

Once it is connected, `selftest_battery.py` confirms the chain non-destructively
- but only after it is plugged in, so the meter comes first.

## The reverse-polarity guard

Two parts, and they turn "meter it every time" into "it does not matter". The
cell comes into a JST, through the guard, and out of a second JST to the host
board's battery connector.

### It does not have to be on this board

It is described here because that is where it was first proposed, but it shares
no net with anything else on the daughter board - the battery never touches the
32-pin header - so it is better off as its own small board, or as nothing more
than a FET and a resistor inline in a heatshrunk pigtail.

Two reasons, and the second is the stronger one:

**It stops waiting on the hard part.** The daughter board's unknowns are the
header and the button stack. The guard has neither, so keeping it separate means
the host board can be protected before the daughter board exists, and a later
change to the header or the caps does not touch it.

**Put it at the host end, not the battery end.** Everything *upstream* of the
guard is protected and everything downstream is not, so the segment between the
guard and the host board is the exposed one. Mounted by the battery, the long
extension is that exposed segment - which is the very cable this exists to
defend against. Mounted at the host board's battery connector with a short
pigtail into it, the extension, the battery connector and every future cell swap
all fall upstream and are covered.

The rest of this section applies wherever it ends up.

### The circuit

```
   cell +  ──┬── [D]  P-FET  [S] ──┬──  to host BAT+
             │         │           │
    JST in   │        [G]          │   JST out
             │         │           │
   cell −  ──┼─────────┴── 100k ───┼──  to host BAT−
             │                     │
            GND ══════════════════ GND
```

| FET pin | Connects to |
|---|---|
| **D** (drain) | cell positive, from the input JST |
| **S** (source) | output positive, to the host board |
| **G** (gate) | ground, through 100 kOhm |

**Drain to the cell, source to the host.** Wired the other way round it looks
identical and protects nothing - see the reasoning below. This is the single
detail to get right, and it is worth checking against the part's own datasheet
pinout rather than a generic symbol, because SOT-23 pin numbering is not
consistent between manufacturers.

Ground is common throughout - the guard is in the positive line only.

### What to buy

A **P-channel MOSFET, logic level**, judged on one number: it must be fully on
at **Vgs = -3.0 V**. Not -4.5 V, not -10 V, which is how most of them are
specified.

That number is not arbitrary. The gate sits at ground, so the FET is only ever
turned on as hard as the cell voltage, and at the end of a discharge that is
3.0 V. A part specified at -4.5 V will be part-way on down there - warm, and
dropping voltage - exactly when the battery is already low.

| Requirement | Why |
|---|---|
| P-channel, logic level | on at Vgs = -3.0 V |
| Rds(on) low, ideally under 50 mOhm at -2.5 V | see the note on the battery readout |
| Vds at least 20 V | trivially met; a 1S cell never exceeds 4.2 V |
| SOT-23 or similar | it dissipates almost nothing |

`AO3401A` and `DMG3415U` are both in the right class and both common. No Zener
across the gate is needed: 4.2 V is nowhere near a typical +/-20 V Vgs rating.

The 100 kOhm gate resistor is not critical - anything from 10 k to 1 M works. It
exists to give the gate a defined potential, not to set a speed.

### Prove it before it meets the host board

Do this with the guard board alone, **nothing connected to the output JST**
except a meter. This is the whole point of building it, and it takes a minute.

1. **Correct polarity in.** Output should read the cell voltage, within a few
   tens of millivolts. A drop of several hundred millivolts means the FET is not
   turning on - wrong part, or the gate resistor is not reaching ground.
2. **Reversed in.** Output should read **0 V**, and must not read negative.
   Brief - a second is enough to see it.
3. **Correct polarity again**, and confirm it comes back. A guard that only
   works once has failed the reversal rather than survived it.

Only after all three does the output JST get connected to the host board.

If you have a current-limited bench supply, use that for step 2 rather than the
cell. If you only have the cell, keep it short.

### Why a diode will not do, and why this orientation

Here for when the schematic is in front of you. Skip it if the circuit above is
already wired.

**The battery line runs both ways.** The AXP2101 charges the cell through the
same two pins it discharges it through. A series diode blocks charging outright,
and its 0.3-0.7 V drop would be ruinous on a cell whose whole useful span is
3.0 to 4.2 V. A MOSFET channel, once turned on, conducts in both directions,
which is what makes it the right part here.

**Normal polarity.** The body diode inside the FET points from drain to source,
so it conducts cell to host on its own. The output rises, which puts the source
at about 3.7 V while the gate is at 0 V, so Vgs is about -3.7 V and the FET
turns hard on - shorting out its own body diode and removing the diode drop.

**Reversed.** The input now sits 3.7 V *below* ground. The gate and source are
both near 0 V, so Vgs is 0 and the channel is off; and the body diode is now
reverse biased, so it blocks too. Nothing conducts.

**Wired the other way round** - source to the cell, drain to the host - the
channel still turns off on reversal, but the body diode ends up forward biased
and passes the reversed voltage straight through. The board looks identical and
protects nothing, which is why the orientation is worth checking twice.

### It changes what the battery gauge reads

The AXP2101 measures the battery at *its* pin, which is now on the far side of
the FET. So the voltage it reports is the cell plus or minus `I x Rds(on)`,
depending on whether it is charging or discharging - and the pendant's charge
percentage is derived from that voltage, so the error lands on the number the
operator reads.

| Rds(on) | Current | Error | On the curve |
|---|---|---|---|
| 50 mOhm | 0.5 A | 25 mV | lost in the noise |
| 50 mOhm | 2 A | 100 mV | ~10 points on the flat middle |

Keep Rds(on) low and it does not matter. The charge current the AXP2101 is
actually set to lives in registers `0x62` and `0x63`, which
`probe_axp2101_map.py` already dumps.

### What it does not protect

**Only what is upstream of it.** The input JST catching a mirrored extension is
the case this solves. The **output lead**, from the guard to the host's battery
connector, is the unprotected link - which is the whole argument for mounting
the guard at the host end, where that lead can be a short fixed pigtail metered
once, rather than at the battery end, where it is the full extension run.

**Not a short circuit.** Reverse polarity is the dead-board failure; a
downstream short is the fire one. That is the cell's protection PCB's job - most
1S packs have one at the terminals. **Confirm yours does.** If it is a bare
cell, a fuse in this line is worth more than the FET.

## Mechanical constraints this board is under

It is pinned by two things at once, which is what makes it harder than its
schematic suggests:

1. **The header fixes its position relative to the host board**, in all three
   axes.
2. **The buttons must reach the enclosure top** through their caps.

So the enclosure's top surface, the host board's mounting, and this board's
thickness and switch height are one dimension chain, not three independent
choices. Fix the host board and the enclosure top first; this board's stack
height is then whatever is left, and the caps absorb the remainder.

## Geometry

**54.50 x 100.00 mm**, with 2 mm chamfers on all four corners. Carried by
`Outline.dxf` and `Holes.dxf` in one shared frame, both exported together.

**The origin is the header's centre in Y and the board's centre in X.** Mixed
on purpose rather than by accident: the header is the datum everything mates
to, and the board is symmetric about its own centreline. So Y = 0 sits on the
header, 39 mm up from the bottom edge, and X = 0 is the board's midline.

| Feature | Position |
|---|---|
| outline | X -27.250 to 27.250, Y -39.000 to 61.000, 2 mm corner chamfers |
| header, 2x16 | columns X **-24.260** and **-21.720**, rows Y **-19.039** to **19.061** at 2.540 |
| header body | X -25.590 to -20.390, Y -20.589 to 20.611 (5.20 x 41.20) |
| **pin 1** | **(-24.260, 19.061)**, in a 1.6 mm crossed box |
| encoder header, 1x6 | Y **58.000**, X **4.000** to **16.700** at 2.540 |
| buttons | Y **53.000**, X **-15.250**, **0**, **15.250** |
| mounting | X **+/-24.250**, Y **58.000 / 36.000 / -36.000** |

Everything is inset **3.000 mm** from the edge it is nearest - the mounting
holes from all four sides, the encoder header from the top. The exception is the
header body, which clears the left edge by **1.660 mm**, and is the tightest
thing on the board.

**Two drill groups, and that is the acceptance test:**

| Diameter | Count | |
|---|---|---|
| 1.0 mm | 38 | 32 header + 6 encoder |
| 2.3 mm | 6 | mounting |

A third group appearing in a future export means construction geometry has
leaked in, which is what happened the first two times - mirrored circles off the
screen standoff, and a leftover 0.8 mm reference at pin 1. The same trick
`carrier-board.md` used with its four drill sizes: keep the expected set small
enough that anything outside it is visible at a glance rather than needing to be
checked.

**The buttons are centre points, not holes**, which is correct - the switch
footprint brings its own pads and drills, and the template only says where to
put it. It also means the switch does not have to be chosen before this file is
useful.

**Pin 1 is a centre point, a box, and both diagonals.** A plain square reads as
incidental geometry; a crossed box reads as deliberate, and nothing else on the
board looks like it. Worth the four extra lines on the connector whose
misorientation is the expensive mistake.

> **The numbers above describe the DXF template, which the PCB has overtaken.**
> The header, buttons and encoder connector all moved during layout, and the
> encoder went from six pins to four. What was actually fabricated is below.

## As built - PSB v1.0

Read out of `PendantPcb/production/PendantPcb.zip`, so these are the numbers a
board house works from rather than the ones the drawing intended.

**54.500 x 100.000 mm**, 8-vertex outline with 2 mm corner chamfers.

| Feature | Position |
|---|---|
| header J2, 2x16 | columns X **2.99** (odd, edge) and **5.53** (even), Y **20.66** to **58.76** at 2.540 |
| **J2 pin 1** | **(2.99, 58.76)** - bottom of the edge column |
| encoder J3, 1x4 horizontal | Y **88.33**, X **41.0 / 38.46 / 35.92 / 33.38** = pins 1/2/3/4 |
| buttons SW3, SW2, SW1 | X **8.25 / 27.25 / 46.25**, pads at Y **90.0** and **96.5** |
| mounting, 6x | X **3.0** and **51.5**, Y **3.7 / 75.7 / 97.7** |

Buttons are **19.0 mm apart and centred on 27.250**, which is the board's own
centre - worth stating because the first layout had them at 19.5 and 18.5 with
the middle one 0.5 mm off, and unequal spacing between three caps is visible
every time once the enclosure is on.

**Four drill groups, and that is the acceptance test:**

| Diameter | Plating | Count | |
|---|---|---|---|
| 0.300 | PTH | 2 | vias |
| 1.000 | PTH | 36 | 32 header + 4 encoder |
| 1.300 | PTH | 6 | three switches, two pads each |
| 2.200 | NPTH | 6 | mounting |

A 1.300 group that is missing means the switches were placed after the export -
which happened, and produced a zip with no buttons on it at all.

**Silkscreen:** `ZERO` `START` `HOLD` over the three buttons left to right,
`+ - A B` against J3 pins 1 to 4, `+BATT` at J2 pin 1, and `PSB v1.0`. Each label
was checked against its pad's coordinates rather than by eye, because `A` and `B`
were briefly attached to the wrong nets and the silkscreen would have inherited
it.

**All of that is on the boards in use except `PSB v1.0`**, which went into the
design after they were fabricated. It is the only difference between a board in
hand and this repo, so a board with labelled buttons and an unlabelled revision
is the first batch rather than a board with something missing.

## The header mapping, verified against the pendant

Measured and confirmed on the physical handheld, 2026-08-16. This is the table
that decides whether the board is correct, and it lived nowhere until now.

| J2 pin | Column | Rows above BATT | GPIO | Function |
|---|---|---|---|---|
| 1 | edge | 0 | - | **+BATT**, isolated pad - see below |
| 2 | inner | 0 | - | VBUS. Measured **0 V** without USB, **4.89 V** with. Deliberately unconnected. |
| 4 | inner | 1 | - | GND |
| 7 | edge | 3 | **38** | `feed_hold` -> SW1, rightmost at X 46 |
| 9 | edge | 4 | **39** | `cycle_start` -> SW2, middle at X 27.5 |
| 10 | inner | 4 | - | marked not connected on the pendant |
| 11 | edge | 5 | **40** | `zero_axis` -> SW3, leftmost at X 8 |
| 12 | inner | 5 | **10** | encoder **B** -> J3 pin 4 |
| 14 | inner | 6 | **9** | encoder **A** -> J3 pin 3 |
| 30 | inner | 14 | - | GND |
| 31 | edge | 15 | - | 3V3. Measured **3.29 V**. Unused. |
| 32 | inner | 15 | - | **+3V3**, measured **3.29 V**, feeds the encoder |

Counted in **rows from the +BATT pad** rather than by pin number, because "pin 9"
means three different things here - the pendant's own pinout, the schematic's
`Conn_02x16_Even_Odd` numbering, and the custom footprint's pads. Rows from an
anchor survive all three. Odd pins run up the edge-most column, even up the
inner one, 2.54 mm per row, with pin 1 at the bottom.

The GPIO column matches `BUTTON_MAP` and `ENCODER_PIN_A/B` in
`micropython/pendant/pendant.py`. If either moves, both have to.

**Pin 32 was the one worth measuring.** The whole 3V3 encoder decision rests on
it being a regulated rail: the wheel is open-collector, so its outputs swing to
whatever supplies it, and they reach GP9 and GP10 with no divider in the way. On
VBAT or VBUS that is over the S3's absolute maximum. 3.29 V says it is the right
rail.

**+BATT is a single-node net** - J2 pin 1 and nothing else on the board. That is
deliberate, and it makes the pad a **post-fab orientation test**: mate the boards
and probe it. Battery voltage means the numbering composes correctly through the
symbol, the footprint and the placement; 0 V or 3.3 V means one of those three
mirrors did not cancel. Safe to probe precisely because nothing else is on it.

### J3, the encoder connector

`PinHeader_1x04_P2.54mm_Horizontal`, four pins rather than the six the DXF
carried. Enough for the pendant - A, B, Vcc, GND - at the cost of not landing
A-/B- for a future RS-422 receiver on a long cable.

| J3 pin | Signal |
|---|---|
| 1 | +3V3 - encoder Vcc |
| 2 | GND - encoder 0V |
| 3 | **A** (GP9) |
| 4 | **B** (GP10) |

**This connector must be labelled on the silkscreen.** It carries 3V3 and GND
adjacent to each other with no keying, so a cable fitted backwards puts reverse
polarity across the wheel. Pin 1 mark plus `3V3 GND A B` costs nothing now and
cannot be added later.

### Silkscreen the board needs

> **Done, and kept as the checklist it was.** This was written when the board had
> no free text at all, and everything on the list reached the design - see the
> silkscreen note under "As built - PSB v1.0" above for what is on it. The last
> item is the
> one that landed late: the version marking went in after the first batch was
> fabricated, which is why the boards in use carry every label below except their
> own revision.

- **J3 pin 1 and its four signals**, per above. The one with a damage path.
- **Button functions** - `HOLD` / `START` / `ZERO`, left to right that is
  `ZERO START HOLD`, since SW3 is leftmost.
- **A power strip** marking 3V3 and GND.
- **Pin 1 on J2.**
- **Board name, revision and date.** This will iterate, and two bare boards in a
  drawer are indistinguishable otherwise.

### Rename the nets

`Net-(J2-Pin_7)` and friends carry no meaning. Renaming them to `GP38`, `GP39`,
`GP40`, `GP9` and `GP10` changes no copper - it is purely the schematic - and it
makes the board checkable against `pendant.py` by anyone, instead of the mapping
existing only in a table like this one and in somebody's memory.

## Getting geometry out of CAD and into KiCad

Two DXFs, same names and same rules as the carrier board, because the
constraints are KiCad's rather than this project's:

| File | Imported to | Contains |
|---|---|---|
| `Outline.dxf` | `Edge.Cuts` | the board outline and any real cutouts |
| `Holes.dxf` | a user layer, e.g. `Dwgs.User` | every drilled position, as a placement template |

**The split is required, not tidiness.** KiCad's Import Graphics puts every
entity in a file onto one layer, so a combined file sent to `Edge.Cuts` gives
you a board outline plus a crowd of circular cutouts - a board that falls to
pieces on the router.

**Imported DXF circles are drawings. They drill nothing.** Real holes come from
footprints; `Holes.dxf` only says where to put them. Import it to a user layer,
place the footprints on the circles, then the layer has done its job.

**Only `Edge.Cuts` cuts.** Geometry on a user layer is inert - it does not cut,
does not drill, and does not reach the fab outputs - so reference geometry that
must not become a feature belongs in `Holes.dxf`, never in `Outline.dxf`. That
is how the header's position gets shown without the router taking it seriously.

**Mark pin 1 unambiguously in the DXF.** A plain rectangle, or a row of
identical circles, can be placed rotated 180 degrees - the same failure the
keying section above warns about, except it happens during layout instead of at
the bench, so the boards come back wrong rather than being caught. A
different-diameter circle, or a small cross offset to one corner, settles it.

Then **place the real footprint on the reference and stop trusting the DXF**.
The imported geometry is a placement target, not the connector: the footprint
carries the pads, and DRC only checks the footprint. Once it is placed, the user
layer can be hidden.

**Generate `Outline.dxf` from `Holes.dxf`** by deleting every circle except any
that are genuine cutouts, rather than drawing the two separately. Exporting them
independently once produced a 180 degree frame flip that would have put every
hole at the wrong end of the board. Same frame, same origin, one source.

What `Holes.dxf` has to carry for this board:

- the **header position**, which is fixed by the host board and is the datum
  everything else hangs off
- the **three switch centres**, fixed by the enclosure top and its cap bores
- **mounting holes**, and the asymmetry that stops the board mating rotated
- **test point positions**, if you want them placed rather than found

Keep the drill sizes to a small set and say what they are. On the carrier board
there were exactly four, which made every footprint checkable by eye - anything
outside those four groups was a mistake.

## Bring-up order

Each step separates a failure the one above it would mask.

1. **Bare board, no host.** Continuity from every header pin to where it should
   land. Confirm no 3V3 to GND short before anything is mated.
2. **Mated, host powered, nothing else fitted.** Confirm 3V3 at the encoder
   connector and at the test point. This is the step that catches a header
   mated one column out.
3. **Buttons.** Meter each line to GND, pressed and released, before trusting
   software. Then run the pendant and press each one - the log names the action.
4. **Encoder.**

   ```bash
   python tools/on_board.py micropython/pendant/probe_encoder.py
   python tools/on_board.py micropython/pendant/monitor_encoder.py
   ```

   The first gives levels and per-channel duty; the second gives decode quality
   over thirty seconds. **`errors` proves nothing on this board** - PCNT counts
   pulses and validates nothing, so it reads zero whatever happens. The two
   signals that carry information are the scale check and the duty split. A
   lopsided duty means one channel is barely transitioning, which is what a bad
   joint looks like, and is how one was found during the 3V3 work.
5. **Whole thing.** `python tools/run_pendant.py`, with the caps and enclosure
   fitted, wearing the gloves it will actually be used in. The button feel is
   the thing that cannot be measured from a bench.

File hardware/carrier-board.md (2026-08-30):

# Pendant carrier board

> **Superseded by [platform-decision.md](platform-decision.md).** The pendant
> moves to an ESP32-S3 all-in-one board with a dedicated link, because an
> open-source pendant cannot require the builder to have usable WiFi - a
> requirement none of the reasoning below was weighed against.
>
> Kept rather than deleted. The electrical and mechanical work here is still
> correct and most of it carries over: the encoder dividers, the argument
> against running the display at 3V3, the dial overhang, the encoder bolt web,
> the button clearance, the wire slot. Only the board that hosts it changed.

First draft off the breadboard. The carrier holds the Pico 2 W, the display, the
two encoder dividers and the buttons, and takes its power from a LiPo Amigo Pro
mounted separately in the case.

Nothing here changes the firmware. Every pin is the one already in
`micropython/pendant/pendant.py`, so a board built to this spec runs the current
`main.py` with no edits — which is the point. The one addition is GP26 for
battery sense, on a pin that was already free.

## Why this shape

The decision to stay on the Pico 2 W rather than move to an all-in-one ESP32
board came down to two measurements, both in the repo's history:

- **Power.** The ESP32 board's real advantage was its AXP2101 doing charging,
  power path, fuel gauge and power button. The LiPo Amigo Pro does the first
  three of those plus the button, as a module, so that advantage mostly
  evaporated.
- **Radio.** Matched at −54 dBm on a dedicated 2.4 GHz channel, the two boards
  split evenly - the Pico owns the floor and median (8/61 ms against 18/75), the
  ESP32 the tail (p99 135 against 265). Neither is ahead by enough to justify
  re-validating a tuned system. `selftest_latency.py` reproduces this.

`quadrature_pcnt.py` stays in the tree as a tested fallback if this board turns
out worse than expected.

## Geometry

> **The DXFs described below no longer contain this board.** `Outline.dxf` and
> `Holes.dxf` were replaced in place by the daughter board's geometry, which
> supersedes this carrier - see [daughter-board.md](daughter-board.md). This
> board's files are recoverable from commit `1a230de` if they are ever wanted;
> the dimensions and reasoning below stand on their own without them.

**162.00 x 56.00 mm**, 1.6 mm FR4. Two DXFs carry it, both in the same frame
with the origin at the display end - X runs 0 to -162, Y runs 0 to -56.

| File | Goes to | Contains |
|---|---|---|
| `Outline.dxf` | `Edge.Cuts` | board outline, the 8 x 5 mm wire slot, the 43 mm encoder cutout |
| `Holes.dxf` | a user layer, e.g. `Dwgs.User` | all 73 drilled positions, as a placement template |

`Outline.dxf` is generated from `Holes.dxf` by removing every circle except the
43 mm one, so the two cannot drift out of alignment. Exporting them separately
once produced a 180 degree frame flip that would have put every hole at the
wrong end of the board.

The split is a KiCad requirement: Import Graphics puts every entity on one
layer, so a combined file sent to `Edge.Cuts` yields a board outline plus 74
circular cutouts. **Imported DXF circles are drawings, not holes** - they drill
nothing. Real holes come from footprints, and `Holes.dxf` only says where to put
them.

| Feature | Position |
|---|---|
| encoder cutout | 43 mm dia at (-132, -28), 50.8 mm bolt circle, 3 x 3.5 mm |
| display mounts | 73.84 x 45.56 mm, 4 x 3.3 mm |
| button column | X = -92, buttons at Y -14/-28/-42, panel screws at -7/-21/-35 |
| wire slot | 8 x 5 mm at X -100..-92, Y -52.5..-47.5 |

Four drill sizes across the whole board - 3.5 x3, 3.3 x4, 2.3 x10, 1.0 x56.
Anything outside those four groups is a mistake, which makes the footprints easy
to check by eye.

**Why 56 mm wide.** It is sized to the display and its bezel. The 60 mm dial
therefore overhangs the board by 2 mm per side, which is deliberate rather than
an oversight: the dial sits above the board, and the case is built out to meet
its bezel flush. The enclosure is wider than the PCB at the wheel end by design.

**Why the buttons sit at X = -92.** They are squeezed between the display and
the dial, and because the dial is round it reaches furthest toward the display
exactly on the centreline - where the middle button is. At X = -92 the middle
button clears the dial rim by 10.0 mm and the display's mounting holes by 13.4
mm. Moving the column either way trades one against the other; no rearrangement
of three buttons widens the corridor they sit in.

## Power

> **Provisional.** This section is designed against the Waveshare module's
> schematic, not against a part on the bench. Confirm it once the display is
> wired and running - particularly the display's actual current at 3.3 V, which
> decides whether the Pico's regulator carries it.

The Amigo Pro has **no boost**. Its DEVICE connector is raw cell voltage,
3.0-4.2 V, limited to about 1 A by the XB6096I2S. The display runs at 3.3 V and
only the encoder wants 5 V, so the sole converter this board has to carry is a
small one for about 30 mA.

```
USB-C ─→ LiPo Amigo Pro ─→ DEVICE (JST-PH, 3.0-4.2 V)
         charge · power path · protection · on/off button
                                    │
                   ┌────────────────┼────────────────┐
                   │                │                │
              Pico VSYS       boost → 5 V      10k/10k → GP26
            (1.8-5.5 V in)          │         (battery sense)
                   │                └─→ encoder Vcc ─→ 22k ─→ GP2/GP3
              Pico 3V3 out
                   └─→ display VCC
```

**The Pico runs straight off the cell.** VSYS accepts 1.8-5.5 V and the Pico's
own buck-boost makes 3.3 V from it, so converting up to 5 V first would be two
conversions where one will do.

**The display hangs off the Pico's 3V3 pin**, for a reason that is not obvious:
a dedicated 3.3 V rail from a single cell cannot be an LDO or a plain buck,
because the cell falls to 3.0 V - below the output. It would have to be a
buck-boost, and the Pico already contains one sized for exactly this input
range, with headroom on the 3V3 pin for external draw. Putting a second one on
the carrier would be paying twice for the same converter.

Everything derives from the switched DEVICE output, so the rails rise and fall
together. That matters: a 5 V encoder feeding dividers into an unpowered Pico
would push current through its protection diodes.

### The Amigo Pro is not on this board

It is a 36 x 23 x 7 mm module that lives in the case. The carrier's entire
interface to it is **two wires, VDEV and GND**, into a 2-pin connector. Design
the enclosure around the module, not the board around the module.

It brings more out than its connectors suggest, and three of those change the
enclosure rather than the carrier:

| Interface | Use |
|---|---|
| DEVICE JST-PH, or the VDEV pad | 3.0-4.2 V into the carrier |
| BATTERY JST-PH, or the VBAT pad | the cell |
| **SW header** | external momentary on/off switch |
| **LED headers** | external charge and status indicators |
| USB-C | the only way power gets in |

So the power button is a **fourth panel-mount button**, wired to the Amigo's SW
header rather than to the Pico. It does not appear anywhere in the firmware and
needs no GPIO. The status LED wants a position on the case too.

**Align the module's own USB-C with a case cutout.** There is no alternative
power injection - USB-C is the only input - so a second receptacle on the
carrier would have to be wired back to the module's own connector pins, which is
a poor mechanical joint in something handheld. One cutout, no extra parts, no CC
resistors.

The battery charges with the output switched off, so the pendant can sit on the
charger overnight while turned off, which is the way it will actually be used.

### Sizing the boost

Estimates, worth confirming with a meter before ordering:

| Load | Rail | Draw |
|---|---|---|
| display logic + backlight | 3V3, from the Pico | 100–150 mA |
| touch controller | 3V3, from the Pico | ~5 mA |
| RP2350 + WiFi | internal | 50–120 mA |
| **encoder** | **5 V, from the boost** | **20–40 mA** |

The 5 V rail carries the encoder and nothing else, so almost any boost will do.
What was a 500 mA converter feeding the whole device is now about 30 mA.

The number still worth measuring is the **display's current at 3.3 V**. It sits
on the Pico's regulator alongside the RP2350 and the radio, and backlight
current rises as voltage falls for the same brightness. There is headroom on
that rail, but headroom is not a measurement.

**Buy the boost as a module for this board.** A boost is one of the easier
things to lay out badly - the switch node loop wants to be small, and a sloppy
one radiates into exactly the two nets that matter here, the display SPI and the
encoder inputs. Let someone else's layout carry that risk on the first
revision.

Prefer a **fixed 5 V** module over an adjustable one. The ubiquitous MT3608
boards set their output with a trimmer pot, which is a part that can be knocked
in a handheld tool that lives in a shop.

### Battery sense

10k/10k divider from the DEVICE rail to GP26, with 100 nF to ground at the pin.

Tapping **before** the boost is the whole point: a boost holds a contented 5 V
right up until it collapses, so sensing after it gives no warning at all. The
cell voltage is the only honest signal.

4.2 V through a 2:1 divider reads 2.1 V, using about two thirds of the ADC's
range. 10k/10k draws 210 µA, which is under 2 mAh across an eight hour shift and
is switched off with everything else. The 100 nF is not optional - the RP2350's
SAR wants a low impedance source for its sampling instant, and the cap supplies
the charge the divider cannot.

Firmware thresholds, once it exists: warn near 3.4 V, shut down near 3.2 V.

## Connections

Every pin below is already in `pendant.py`. GP26 is the only new one.

### Encoder — 4-pin connector

| Signal | Goes to | Note |
|---|---|---|
| A | GP2, via 22 kΩ to GND | divider — see README |
| B | GP3, via 22 kΩ to GND | |
| Vcc | 5 V rail | **not 3V3** |
| 0 V | GND | |

The handwheel is a push-pull line driver swinging a full 0–5 V, and the RP2350
is not 5 V tolerant. Its internal ~10 kΩ pull-up forms the upper half of the
divider; 22 kΩ puts the high level at 3.06 V, best centred against the input
threshold. The two 22 kΩ resistors are the entire passive BOM of the original
breadboard.

### Display — SPI

| Pin | Signal |
|---|---|
| GP17 | CS |
| GP18 | SCK |
| GP19 | MOSI |
| GP20 | DC |
| GP21 | RST |
| GP22 | backlight |
| — | VCC to 5 V rail, GND |

`SDO/MISO` and `SD_CS` stay unconnected - the panel is written to, never read,
and the SD slot is unused.

**Use Interface 1, the 18-pin 0.5 mm FPC.** The module offers two host
interfaces and both carry display and touch together, so either would work
electrically:

| | Interface 1 | Interface 2 |
|---|---|---|
| Type | 18-pin FPC, 0.5 mm | **JST GH**, 15-pin, 1.25 mm |
| Cable | flat flex, **supplied with the module** | crimped harness |
| Carrier part | 18-pos 0.5 mm ZIF socket | `SM15B-GHS-TB` header |
| Cable parts | none to buy | 2x `GHR-15V-S` + 30x `SSHL-002T-P0.2` |

Interface 2 looked the better choice while it was mistaken for a coarse-pitch
FPC - 1.25 mm is far kinder to solder than 0.5 mm, and a GH latch holds better
under vibration than a ZIF actuator. Two things settle it the other way.

**Height.** GH is wire-to-board. The module stands **10.3 mm tall including its
standoffs**, with both connectors on the underside roughly level with them, so
there is about 4 mm of gap. A mated GH plug is 3.4-5 mm before the wires have
bent, which does not fit. Flat flex is under 1 mm and turns tightly.

**The cable ships with the module.** That removes the three specs that would
otherwise each have to be guessed correctly - pitch, length, and whether
contacts sit on the same or opposite faces at the two ends. Two of those three
mirror the pinout silently when wrong.

What the supplied cable does decide is whether the socket must be **top or
bottom contact**. Do not reason it out: plug the cable into the module, route it
to where the socket will sit, and look at which face the exposed contacts
present. Measure its length too - it constrains how far from the module the
socket can be placed.

A ZIF actuator holds less firmly than a latch and this is a tool that gets
carried around a shop, so add a retainer or a dab of RTV once it is working. And
solder the socket before anything tall goes on the board, while an iron can
still lie flat.

One connector carries the whole module - display and touch both - and every
signal lands on a pin the firmware already uses:

| FPC | Signal | Goes to |
|---|---|---|
| 1 | VCC | Pico 3V3 |
| 2 | LCD_BL | GP22 |
| 3 | GND | GND |
| 4 | LCD_SCLK | GP18 |
| 5 | LCD_MOSI | GP19 |
| 6 | LCD_MISO | unconnected - the panel is written to, never read |
| 7 | LCD_DC | GP20 |
| 8 | LCD_RST | GP21 |
| 9 | LCD_CS | GP17 |
| 10 | SD_CS | unconnected - the card slot is unused |
| 11, 16-18 | NC | - |
| 12 | TP_RST | GP13 |
| 13 | TP_SCL | GP11 |
| 14 | TP_SDA | GP10 |
| 15 | TP_INT | GP12 |

Interface 2 additionally brings out the module's regulated **3V3** rail, which
Interface 1 does not. That is the LDO's output, so driving it externally would
bypass the regulator and recover the ~90 mV it drops. Not worth back-feeding a
regulator for, and moot on Interface 1.

**The hole pattern in Holes.dxf - 73.84 x 45.56 mm - comes from Waveshare's own
supplied CAD**, so it is already the right module. Still worth a caliper against
the physical part before the outline is committed: vendor CAD and vendor
hardware occasionally disagree, and a mounting pattern is an expensive thing to
find wrong after the boards arrive.

**The display runs at 3V3, and 5 V would be worse.** This is vendor-specific and
was decided the other way for the module that came first, so it is worth setting
down why it changed.

Both modules regulate VCC down to 3.3 V on board. The difference is the part.
LCDWiki's used an AMS1117-class LDO with about 1.1 V of dropout, so a 3.3 V
input could not produce 3.3 V and the backlight visibly dimmed. Waveshare's uses
an **ME6217C33M5G** - 3.3 V, 800 mA, **180 mV dropout at 300 mA**. At this
board's load the drop is nearer 90 mV, so 3.3 V in gives about 3.2 V on the
panel rail, inside spec for both the ST7796S and the FT6336U.

Feeding it 5 V is the worse option, not the safe one: that same LDO would
dissipate (5 - 3.3) x 150 mA, roughly **255 mW**, in a SOT-23-5 under the screen
of a sealed handheld - and you would have bought a 500 mA boost in order to
create the heat. At 3V3 the regulator sits in dropout doing almost nothing.

The module also carries a **TXS0108E** level translator. With VCC and the panel
rail both near 3.3 V it is essentially passing through, which is the kindest
case for it. If the panel ever shows corruption or fails to initialise, drop the
SPI baudrate before suspecting the driver - that part has a reputation for being
marginal on fast SPI.

### Touch — I2C1

| Pin | Signal |
|---|---|
| GP10 | SDA |
| GP11 | SCL |
| GP12 | INT |
| GP13 | RST |

Level converted on the touch module, so 3.3 V logic is safe against it.

### Buttons — to GND, internal pull-ups

| Pin | Action |
|---|---|
| GP7 | feed hold |
| GP8 | cycle start |
| GP9 | zero axis (long hold only) |

Panel-mount rather than PCB tactile: this is handled with gloves, with chips
about, and a panel button is the more robust part. Axis and step selection are
on the touch panel and need no pins.

There is a **fourth** panel-mount button, for power, but it belongs to the Amigo
Pro's SW header and touches neither this board nor the firmware. Worth counting
when laying out the case.

**No E-stop on this board.** Feed hold and cycle start over WiFi are fine -
worst case they are late. An E-stop that depends on an associated radio link is
not an E-stop, and a big red button teaches the hand the wrong reflex.

### Still free after this board

GP0, GP1, GP4, GP5, GP6, GP14, GP15, GP16, GP27, GP28.

## Layout notes

- **Socket the Pico.** 2×20 female headers. It makes the module replaceable,
  survives a bad joint, and leaves the carrier reusable.
- **Keep GP2/GP3 away from the SPI bus.** The display switches hard at tens of
  MHz next to the two most timing-critical inputs on the board. Opposite sides,
  ground pour between.
- **Design the outline to the display's mounting holes** and stack the carrier
  behind it. Board-to-board is stronger than a ribbon, and it fixes the
  enclosure dimensions for you.
- **Check the battery connector polarity.** JST-PH on LiPo cells is not
  standardised between vendors and plenty of boards have died to a reversed
  pack.

### Footprints to place and leave empty

They cost nothing unpopulated and each one saves a respin:

- Pull-ups on A/B to 3V3, in case the encoder is not the line driver it appears
  to be
- Series-R and cap pads for an RC filter on A/B
- ESD diodes on the encoder lines - a handwheel cable in a shop with a concrete
  floor is a real path into a GPIO

### Test points

The bring-up order in the README is only runnable with a meter if the nets are
reachable. Pads on: cell (DEVICE), 5 V, 3V3, encoder A and B raw, both divider
outputs, GND.

## Bring-up order

Same layering as the README, each step separating a failure the one above would
mask:

1. **Power only.** No Pico seated. Confirm the DEVICE rail, the 5 V rail, and
   that the Amigo's button gates both. Confirm charging works with the output
   off.
2. **Pico seated, nothing else.** `smoke_test.py`.
3. **Encoder.** `selftest_quadrature.py` for the decode, then
   `monitor_encoder.py` on the real wheel. Watch `errors` - it should stay at
   zero, and a climbing value means the dividers or the routing are wrong.
4. **Display.** `selftest_display.py`, then `selftest_st7796.py`.
5. **Touch.** `selftest_touch.py`.
6. **Link.** `selftest_link.py` against `tools/mock_sender.py`, then
   `selftest_latency.py` for a number to compare against the bench figures
   above.
7. **Whole thing.** `tools/run_pendant.py`.

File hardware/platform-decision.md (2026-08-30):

# Platform and link

The pendant moves to an ESP32-S3 all-in-one board with a dedicated ESP-NOW link
to a USB-attached receiver. This reverses the decision in
[carrier-board.md](carrier-board.md), and the reason is worth setting down,
because the earlier reasoning was not wrong - it was answering a different
question.

## The requirement that changed

Everything before this was tuned around one shop: which channel was quiet, where
the access point sat, whether the sender could reach Ethernet. All of it
sensible, and all of it beside the point.

**An open-source pendant cannot require the builder to have usable WiFi.** Plenty
of shops are detached, steel-clad, or have no coverage at all. "Works if your
network is good enough" is not a specification anyone else can satisfy, and it
turns every reproduction into a networking support thread.

That single requirement rules out the whole approach the earlier documents
assume - joining the user's network and finding the sender on it - regardless of
how well it measured here.

## What it rules out, and what it leaves

The pendant needs a link it brings with it. Three ways to get one:

| | Pendant hardware | Encoder | Radio work |
|---|---|---|---|
| Pico W pair, receiver as SoftAP | the carrier board | hard IRQ, working | none, reuses the stack |
| RP2350 all-in-one + nRF24 | prebuilt | hard IRQ, working | own the link layer |
| **ESP32 all-in-one + ESP-NOW** | **prebuilt** | **PCNT, tested** | **turnkey** |

nRF24 loses on the same ground that decided everything else. Its modules are a
market lottery - counterfeit silicon, unmatched antennas, missing decoupling,
and folklore that begins "solder a capacitor across the power pins". Tolerable
on one bench, poison for a project whose point is that a stranger can build it.

The Pico W pair is the smallest change and would have been the right first
experiment under the old framing. It loses because it cannot reach the prebuilt
hardware: the RP2350 all-in-one board has no radio at all, so a WiFi link means
building the carrier board anyway.

## Why the all-in-one board decides it

The BOM is the argument:

| Part |
|---|
| ESP32-S3-Touch-LCD-3.5 |
| MPG handwheel |
| 3 x panel-mount buttons |
| LiPo cell |
| Enclosure |

**No discrete parts at all.** The 5 V boost module and the 22 kOhm pair were on
this list until 2026-08-15; both are gone, measured out rather than reasoned
out - see "The encoder runs at 3V3" below. Five orderable items, no passives,
which is a stronger version of the argument this section is making.

No carrier PCB, no charger module, no power-path IC, no battery sense divider,
no power button wiring, no display connector. Someone can order that list and
start. The Pico route needs them to fab a board first, which is a different kind
of project.

Two things on that board that the Pico cannot match at all:

- **An IPEX connector for an external antenna**, via resoldering one resistor.
  For a handheld carried around a steel machine this is worth more than any
  latency figure measured here - the Pico 2 W's antenna is fixed.
- **AXP2101** doing charging, power path, fuel gauge and the power button, with
  a switching charger rather than the linear one the Amigo Pro uses.

It also carries an audio codec and speaker header, which makes an audible probe
complete or alarm possible on a tool used while watching the cut rather than the
screen, and 8 MB PSRAM, enough for a full 320x480x2 framebuffer.

## Already settled

- **PCNT decoding is proven.** `quadrature_pcnt.py` passed on hardware first
  run - direction, scale, lossless `take()`, the wrap handler, and every speed
  row clean to 62,863 edges/s against the 2,000 a hand produces. This was the
  risk that looked largest and it is retired.
- **The display driver transfers.** The board carries the same ST7796S and
  FT6336U panel already ordered for the Pico, so `st7796.py` and `touch.py`
  apply unchanged.
- **The power subsystem is the board's problem now.** Charger, power path,
  protection, fuel gauge and on/off button are all on it.
- **5 V is USB only.** The schematic has three power nets - VBUS, VBAT, VSYS -
  and one power IC, the AXP2101, whose outputs all step down. There is no net
  called 5V and no boost anywhere. This was read as "the encoder still needs a
  small 3V3 to 5 V boost, about 30 mA"; it turned out the encoder did not need
  5 V at all. See below.

## The encoder runs at 3V3, so there is no boost

Measured 2026-08-15. The encoder runs from the board's regulated 3V3 with
**both 22 kOhm removed**, and that is better than the arrangement it replaces
rather than merely cheaper.

**The interface was never the problem.** This wheel is open-collector with an
internal pull-up, so its output level is whatever its own supply is. On 3V3 with
nothing external it presents a clean 3.3 V high straight to the GPIO. The old
5 V arrangement put 5 V through a 22 kOhm to ground and landed at **3.06 V** -
so the "under-driven encoder" the README warned about describes the *previous*
wiring more than this one. Against the ESP32-S3's ~2.48 V input-high threshold,
3.3 V has the better margin.

**The resistors have to come out with the supply change, not after it.** Keeping
them at 3V3 divides against the internal pull-up and gives about **2.06 V**,
under the threshold on both the RP2350 (~2.15 V) and the S3 (~2.48 V). That
fails intermittently, which is the worst way for it to fail.

**Do not take encoder Vcc from the battery rail.** Because the level follows the
supply, VBAT puts 4.2 V on a pin whose absolute maximum is about 3.6 V - and it
sags to ~3.2 V as the cell drains, so the level moves with the state of charge.
The regulated rail holds it still for the whole discharge. It is a buck from the
cell, so it can droop slightly near cutoff, but 3.2 V worst case against a
2.48 V threshold is not a margin worth engineering around.

**Evidence.** `monitor_encoder.py`, 30 s at 3V3: **4,173 detents, 16,695
counts**, sustained 100-195 detents/s, peak 195.5, no dropouts and no rate
collapses, three counts unaccounted at the end which is where the wheel stopped.
`probe_encoder.py`: low 0.12 V, high >= 3.22 V, duty **48/52 and 49/51**.

Note that `errors` proves nothing on this board - PCNT counts pulses and
validates nothing, so it reads zero whatever happens. The two signals that do
carry information are the scale check and the per-channel duty; a lopsided duty
is how a bad joint on one channel was found during this work.

## Measured

ESP-NOW between the ESP32-S3 board and an ESP-WROOM-32, on the bench, against
the TCP link measured the same way - same 200 samples at 50 ms, same
percentiles. See `selftest_espnow.py` and `selftest_latency.py`.

| | ESP-NOW | TCP | |
|---|---|---|---|
| min | 9.36 | 8 | same |
| **median** | **9.76** | 61 | **6.3x** |
| mean | 15.02 | - | |
| p90 | 19.82 | 90 | 4.5x |
| **p99** | **59.77** | 207 | **3.5x** |
| max | 60.12 | 217 | 3.6x |

200/200, nothing unacknowledged, nothing silent.

**The tail is the result.** The test was written to distinguish two
explanations: if the median improved but p99 did not, the ceiling would be the
2.4 GHz environment and leaving the infrastructure behind would buy
determinism without buying latency. The p99 improved 3.5x, so the ceiling was
the network stack - association, beacons, access point scheduling and the
sender's own WiFi hop - and removing the infrastructure removed them.

The other tell is that **median sits on top of min**, 9.76 against 9.36. Almost
every sample is at the floor, so the link adds no queuing delay of its own.
Under TCP a median of 61 against a min of 8 meant nearly every packet paid
overhead.

In the units that matter: 9.8 ms is **0.41 mm** at 2500 mm/min, against a lag
budget of 13-17 mm. Transport has stopped being a term in the equation.

Bench figures, not shop figures, and both ends are MicroPython - C would be
quicker again.

### What the shop said, and why it changes the argument

The TCP column above is a **bench** figure. Measured again at the machine, over
a dedicated 2.4 GHz SSID, with the pendant on it and the sender's PC on a
different 5 GHz SSID - two wireless hops and a routing step:

| | bench TCP | shop TCP |
|---|---|---|
| min | 8 | 16 |
| median | 61 | 68 |
| p90 | 90 | **86** |
| p99 | 207 | **173** |
| max | 217 | 222 |

200/200 received, zero lost, one session. **The tail is better than the bench**,
across a topology chosen to be pessimistic.

That was measured while chasing motion that stumbled and would not recover, and
it is the reason the whole line of enquiry turned around. The faults were all
found elsewhere, each ruled in or out by measurement:

- the **DRO redraw** blocking the pendant's event loop for up to 82 ms, four
  jog ticks, invisible because the watchdog threshold was 100 ms
- the **planner depth target**, fitted for a 5000 mm/min machine and too
  shallow once `$110` reached 15000
- a **run-ahead bound** that could stop the planner filling but never restart
  it, so lag grew to 521 mm and stayed
- an **orphaned sender process** holding the port with no window

None of them transport. The same jog stream replayed from the PC over loopback
- `tools/replay_pendant.py`, no radio in the path - reproduced the fault exactly
when the pendant did and ran smooth when it did not.

**So the honest case for ESP-NOW is not latency.** 68 ms median with a 173 ms
p99 was never what made the pendant stumble, and a link seven times quicker
would not have fixed any of the four faults above. The 6.3x is real and it is
worth having, but it buys headroom rather than solving a problem.

The argument that survives intact is the one at the top of this document: an
open-source pendant cannot require the builder to have usable WiFi. That is a
**reproducibility** argument, not a performance one. This shop's network turned
out to be fine; the point is that the next builder's need not be, and no amount
of tuning here can make that true for them.

Worth stating plainly because the numbers above are seductive: anyone reading
this later - including whoever wrote it - should not conclude that ESP-NOW
fixed a latency problem. It did not have one to fix.

### Then ESP-NOW ran at the machine, and it holds

The whole chain, moving a real axis: pendant to receiver over ESP-NOW,
receiver on `main.py` presenting a serial port, `tools/espnow_bridge.py`
carrying that to the port the sender already listens on. The sender itself is
unmodified - it still thinks it is talking to a TCP pendant - which is the
point of doing it in that order.

**Feel is at parity with WiFi**, judged back to back on the same machine in the
same session, with run-off perceived as slightly *less* over ESP-NOW. The
numbers agree that nothing much changed:

| | WiFi | ESP-NOW |
|---|---|---|
| 0.5 mm peak lag | 77.6 mm | 83.5 mm |
| 1.0 mm peak lag | 112.7 mm | 96.0 mm |
| planner depth reached | 10-12 | 10 |

Equivalent, and that is the expected result once the mechanism is understood:
**lag is set by the run-ahead bound, not by the transport.** The fill runs up
to whatever the bound allows, so lag lands near the bound however quick the
link is. A faster transport does not lower it.

That leaves the reproducibility argument as the whole case for ESP-NOW, exactly
as the section above concluded - now with the reassurance that adopting it
costs nothing in feel.

### ESP-NOW measured in the shop, at last

Every ESP-NOW figure above was taken on a bench. Repeated at the machine, at
two positions, with the responder's own counts as the check:

| | bench | shop, near | shop, far |
|---|---|---|---|
| median | 9.76 | 9.86 | 9.86 |
| p90 | 19.82 | 29.63 | 29.84 |
| p99 | 59.77 | 79.97 | 59.78 |
| **max** | **60.12** | **139.39** | **89.84** |

Four replies unacknowledged across roughly 400 - about **1% loss** - and the
medians are indistinguishable from the bench. The link is good in the shop.

**The tail is not.** The maximum is twice the bench figure, and that is the
number that matters, for a reason worth stating plainly because it inverts the
headline comparison at the top of this document:

- **median**: ESP-NOW 9.86 against TCP's 68, about **7x** better
- **maximum**: ESP-NOW 139 against TCP's 222, about **1.6x** better

The 7x is what makes ESP-NOW look compelling. The 1.6x is what it can actually
be spent on, because everything downstream is sized against the worst case
rather than the typical one.

That resolves the failed bound. It has to clear planner depth plus a worst-case
round trip, and depth is a fixed 0.24 s:

    bench maximum:  0.24 + 0.060 = 0.30 s   ->  0.35 clears it
    shop maximum:   0.24 + 0.139 = 0.38 s   ->  0.35 cuts into it

Sized from the wrong maximum. Not RF loss, not a blocking radio call, both of
which were confidently diagnosed and wrong - just a bench number used where a
shop number was required. **~0.45 is what the measurement supports**, worth
about 10% of the run-off rather than the 30% predicted from bench figures.

**0.45 was then tried at the machine, and the bound stays at 0.5.** The numbers
moved as predicted - peak lag 102 mm down to 88, about 14% - and none of it was
worth having: the operator reported 0.5 as the smoothest of the two with no
noticeable difference in run-off. Reverted, and the per-transport mechanism
with it, since there is now no second value to carry.

So the run-ahead bound cannot be moved by changing transport, and that is the
final word on it. The reason is in the table above: the bound is sized by the
worst case, ESP-NOW's worst case is 139 ms against WiFi's 222, and 83 ms of
headroom on a 0.24 s depth is not enough to matter. **ESP-NOW's value is
reproducibility. It is not a performance change, and three separate attempts
to spend it as one have now failed** - once on a bench extrapolation, once on
a wrong maximum, and once at a value the measurement did support.

One caution for anyone re-running this. The first attempt reported 108/200
received and 90 "acknowledged but never answered", which read as catastrophic
asymmetric loss and produced two hardware conclusions before the responder's
own terminal contradicted both. The pinger matched replies against a sequence
byte and never resynchronised, so a single late answer put the stream
permanently off by one. Fixed, and late replies are now counted separately -
but the general lesson stands: **the responder's count is the check on the
pinger's, and only both terminals together can tell a late packet from a lost
one.**

### The loop stalls are the backpressure. Do not remove them

Over ESP-NOW the pendant reports around **twelve loop stalls a session, worst
case 100 ms**, where WiFi reports one. That looked like a defect for a while.
It is not, and this section exists so nobody tries to fix it again.

Timing the sends found the cause immediately:

    stall=1/38ms    tx=35/56ms
    stall=12/100ms  tx=132/104ms

`tx` counts sends taking half a jog tick or longer. 132 of them, worst 104 ms,
against a worst stall of 100 ms - the same event. `ESPNow.send()` is
synchronous: it waits for the peer's radio to acknowledge, inside the event
loop, so the jog tick waits with it.

**Removing the wait removed the stalls and made the pendant unusable.** With
`sync=False` the `tx` counter stopped climbing after the first sample and the
stall count froze, exactly as intended - and motion fell apart: planner depth
0 of 5, lag pinned at 98.9 mm and never recovering, 67% of the operator's
detents discarded. Rough at every step size.

Because the blocking send *is the flow control*. It paces the pendant to what
the radio can actually carry. Without it, messages go out faster than the link
delivers them, whatever fails to arrive is distance the machine never travels
while the pendant has already counted it, and that gap becomes permanent lag -
which pins the run-ahead bound, starves the planner, and discards two thirds of
the input.

So a 104 ms send is the radio applying backpressure, and the loop stalling is
how the pendant obeys it. The stall counter is measuring a working mechanism.

Worth recording the shape of the mistake as well as the finding. Five changes
were made to this transport chasing better numbers - a hysteresis band, three
values of the run-ahead bound, and this - and all five were reverted after the
machine disagreed. Every one optimised against something measurable: stall
counts, latency percentiles, depth-plus-round-trip arithmetic. The measurements
were sound each time; the inference from measurement to feel was not. **On this
subsystem the operator's report is the ground truth and the counters are
supporting evidence, not the other way round.**

**PSRAM costs nothing.** Repeated on the `SPIRAM_OCT` build, where MicroPython's
heap lives in external RAM rather than internal SRAM and could plausibly have
shown up as latency: min 9.81, median 9.92, p90 19.92, p99 39.90, again 200/200.
The median moved 0.16 ms, which is noise. The tail reads better but two runs
cannot separate that from run to run variation, so the claim is only that
nothing was lost.

That matters because the framebuffer headroom depends on it - `gc.mem_free()`
reports 8.3 MB against 226 KB on the plain build, and a 320x480x2 buffer needs
307 KB. So a full-frame update is affordable without paying for it in latency.

## The board's own pin map

Not in Waveshare's wiki or readable from the schematic PDF - taken from their
demo code at github.com/waveshareteam/ESP32-S3-Touch-LCD-3.5, examples 08 and
11, which agree.

| Signal | GPIO |
|---|---|
| LCD MOSI | 1 |
| LCD MISO | 2 |
| LCD DC | 3 |
| LCD SCLK | 5 |
| LCD backlight | 6 |
| **LCD CS** | **none** |
| **LCD RST** | **TCA9554 at 0x20, pin 1** |
| I2C SDA / SCL | 8 / 7 |
| FT6336U touch | 0x38 on that I2C, polled - no INT or RST pin |

An I2C scan confirms it: 0x18 ES8311, **0x20 TCA9554**, 0x34 AXP2101, 0x38
FT6336U, 0x51 PCF85063, 0x6b QMI8658. The TCA9554 is not in the board's
advertised feature list and answers writes but not reads, so a scan alone only
tells you something is there.

Touch is a drop-in: chip id 0xA3 reads 0x64 and vendor 0xA8 reads 0x11, exactly
what `touch.py` already checks. Only the pin numbers change, and INT and RST can
be dropped.

**`st7796.py` needs two changes**, neither large:

- **No chip select.** The panel is permanently selected, so the driver has to
  tolerate `cs=None` rather than toggling a pin that does not exist.
- **Reset is an I2C write**, not a pin. Waveshare's sequence is TCA pin 1 high,
  10 ms, low, 10 ms, high, 200 ms. Cleanest fix is for the driver to take a
  reset *callable* instead of a pin, so the caller supplies either a pin toggle
  or an expander write and the driver stays platform-agnostic.

Everything else - the init sequence, MADCTL, INVON, the framebuffer push - is
unchanged, because it is the same ST7796S behind it.

## Display: verified, and it cost nothing

Brought up on the board with the two driver changes above and nothing else.
`ROTATION = 0`, 320 x 480, red green and blue correct at the first attempt, and
a four-corner test lands where it should with the USB-C port at the bottom.

So the MADCTL value and `INVON` worked out for the other vendor's module are
right for this one too - the panel is oriented the same way. `st7796.py` and the
whole of `screen.py` transfer intact, including the portrait layout, the DRO
digits, the step grid and the probe page. None of it needed touching.

USB-C at the bottom also matches the reference pendant this is modelled on,
where the cable exits the bottom edge, so it suits the enclosure rather than
fighting it.

## Still open

- **Meter pin 2 on battery.** The schematic says USB only; some PMICs in this
  family have an OTG boost a parts list would not reveal. Ten seconds, once a
  battery exists.
- ~~**The encoder against the real wheel.**~~ Done. On GPIO9 and GPIO10 with the
  22 kOhm dividers and 5 V from header pin 2, one aligned revolution reads
  **exactly 400 counts** - 100 detents, full 4x decode, nothing lost. Reversals
  tracked cleanly over several thousand counts at around 185 detents/s.

  That number is the diagnostic, not a formality. PCNT cannot report illegal
  transitions the way `quadrature.py` does, so counts per revolution is what
  replaces the `errors` counter: an exact multiple of 400 says every edge was
  seen, and anything not divisible by four, or drifting across repeated turns,
  is the tell. Worth re-running once it is in the enclosure on a longer cable.

  An earlier attempt read 268, which was a turn judged by eye rather than a
  decoder fault - align the dial before trusting a single revolution.
- ~~**ESP-NOW at the machine.**~~ Done as far as *feel* goes: it drives the
  machine, at parity with WiFi, with slightly less run-off. See above.

  ~~**What is still unmeasured is its latency there.**~~ Measured: medians
  matching the bench, about 1% loss, and a tail twice as long as the bench's.
  See above. That accounts for the run-ahead bound that failed, and it caps how
  much the quicker link can buy at roughly 10% of the run-off.

  Still open, and unaffected by any of the above: whether the IPEX
  external antenna earns its place. On WiFi at the machine the board reported
  **-37 to -62 dBm** depending on where it was held, with zero lost packets at
  either end of that range - comfortable, and suggesting the internal antenna
  is adequate here. But that is a different protocol on a different band plan,
  and says nothing about a shop with more steel in the path.
- **Pairing.** ESP-NOW addresses by MAC. Needs a story for someone who owns two.
- ~~**Sender transport.**~~ Done. `PendantService` reads the receiver's serial
  port as well as listening on TCP, through an `IPendantChannel` that made the
  serial implementation an addition beside the TCP one rather than a change to
  it. The JSON-lines protocol did not change at all. Both transports stay, one
  pendant active at a time, newest wins - claimed by the accept on TCP and by
  the `hello` on serial, since the receiver's port is open whether or not a
  pendant is switched on.

  `tools/espnow_bridge.py` is retired by this and must not be left running: the
  port is exclusive, so it and the sender cannot both hold it.

  Verified against a receiver end to end - port opened and held, the start-up
  `rx_note` parsed without faulting, clean shutdown. **Not** yet driven by a
  pendant over the radio, which is the half that remains.
- **Registering a board should be one command.** Setting up a receiver is
  currently: run `tools/board.py`, read a serial number off the screen, paste it
  into `BOARDS`, then `sync_board.py --receiver`. The paste is the only manual
  step in an otherwise scripted process, and it is the one most likely to be got
  wrong - the ids are sixteen hex digits and the two ESP32-S3s enumerate
  identically, so a slip puts the receiver's firmware on the pendant.

  A `--register <name>` writing the attached board's id straight into `BOARDS`
  would collapse those two steps into one. It would also retire two notes that
  exist only because the step is manual: the "every id in BOARDS is this
  bench's" warning in `board.py`, and the matching first-time paragraph in the
  README.

  Deliberately not built yet. Every id in `BOARDS` is still this bench's, and
  what defaults to ship is not knowable until the hardware is settled -
  automating the paste before then automates a shape that is still moving.
- **Broadcast the jog messages.** The most promising untried idea on this link.

  ESP-NOW unicast is acknowledged and retried at the 802.11 MAC layer, and that
  is not optional - it is what makes a send take up to 104 ms and stall the
  loop. Declining to *wait* for it, with `sync=False`, does not help: the
  retries still happen, and the pendant simply gets ahead of the radio until
  the driver queue overflows silently. That was measured and reverted.

  Broadcast frames are neither acknowledged nor retried. That removes the cost
  rather than hiding it, and this protocol is unusually well suited to losing
  packets: `protocol.py` sends a detent count and a step size rather than a
  target position, precisely "so a dropped message loses a little motion
  instead of desynchronising a position the two ends would then disagree
  about". At the ~1% loss measured here, a lost jog is 0.1-1 mm the operator
  corrects with the wheel without noticing - which already happens whenever the
  emission cap discards a detent.

  Keep `hello` and `ping` unicast so discovery and pairing are unchanged. The
  receiver already registers a broadcast peer, so it would hear them today.

  What to watch: this removes the flow control the blocking send currently
  provides, exactly as `sync=False` did. The difference is that it also removes
  what that flow control existed to absorb, since with no retries the
  per-packet cost is constant and small. That is the assumption to test rather
  than to trust.
- **Coarse-step block quantisation.** A hypothesis with arithmetic behind it and
  no measurement yet.

  The operator reports minor bumps at 1.0 mm that the stall counter never sees,
  while 0.1 mm is smooth. The pendant can only send whole detents, and per tick
  it wants to send what the commanded feed drains:

      0.1 mm at F2500   ->  0.83 mm per 20 ms tick  ->  8.3 detents
      1.0 mm at F10000  ->  3.33 mm per 20 ms tick  ->  3.3 detents

  Rounding 8.3 is a 12% swing in block length. Rounding 3.3 is **33%**, and the
  surplus is discarded rather than banked, so the depth regulator picks 3 or 4
  tick by tick. `jog.py` already warns what unequal blocks feel like: "blocks of
  unequal length take unequal time at a fixed feed, so a short one landing on a
  shallow planner is a stumble".

  Confirming it means seeing block lengths alternate 3, 3, 4, 3. The trace
  tables used to show that and are off for machine work because printing blocks
  the loop, so it needs a cheaper instrument - the spread of emitted detent
  counts in the periodic one-liner would do.

  If it holds, the options are carrying the fractional residual so the average
  comes out right, or accepting that 1.0 mm at a 20 ms tick has inherently
  coarse blocks.

## What carries over

Most of it. The transport changes; almost nothing else does.

- **Every jog constant**, in the sense that none of them is a network property.
  `MIN_RUNAHEAD_MM`, the planner targets, the feed tables and the turn-rate
  window are machine and planner physics, and a change of transport does not
  touch them.

  What was written here before - that they carried margin because they were
  fitted on a shared network - was wrong, and worth leaving corrected rather
  than deleted. They were fitted against a **5000 mm/min** machine. Once `$110`
  reached 15000 several of them were badly off, and the coarse steps were
  unusable until they were refitted at the machine: `PLANNER_TARGET_BLOCKS` 6 to
  12, `STEP_MAX_FEED` trimmed to 8000 and 10000 at the coarse steps, and
  `RUNAHEAD_LIMIT_S` tried at 0.35, 0.4 and 1.0 before settling back at 0.5.

  The lesson generalises past this project: these constants are fitted to a
  *specific* machine's `$110` and `$120`, and anyone reproducing this on
  different hardware should expect to refit them. The figure that makes that
  tractable is planner depth, now reported in the pendant's periodic one-liner -
  without it, a target never being reached and a target set too low look
  identical.
- **The enclosure work.** The board outline changes; every constraint solved in
  CAD does not - encoder body depth driving the case, the 60 mm dial overhanging
  the board, buttons squeezed between display and dial, the wire pass-through,
  the force distributor and its ring rather than a boss.
- **The encoder wiring.** 5 V line driver, 22 kOhm dividers, the same argument
  against running it at 3V3.
- **`quadrature.py` and the hard-IRQ path**, which stay in the tree. If ESP-NOW
  disappoints, the Pico W pair is still there and still works.

## The receiver stays a separate device

Tempting to fold it into the PICOGPIO controller, which is already a
host-attached microcontroller on USB CDC. It should not be:

- That protocol's core rule is that the device **never sends unsolicited output**
  other than its banner, so a host can identify the port. A pendant stream is
  continuous and unprompted at up to fifty messages a second, which breaks the
  rule immediately.
- GPIO drives vacuum, lights and coolant. Those should not stop working because
  the radio firmware wedged.
- Two different watchdogs with two different meanings on one event loop.
- They want to be in different places - the GPIO board near the relays, the
  receiver where its antenna can see the operator.

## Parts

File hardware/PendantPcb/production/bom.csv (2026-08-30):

Designator | Footprint | Quantity | Value | LCSC Part #
J2 | PinHeader_2x16_P2.54mm_Vertical_Left | 1 | Conn_02x16_Even_Odd
J3 | PinHeader_1x04_P2.54mm_Horizontal | 1 | Conn_01x04_Socket
SW1, SW2, SW3 | SW_PUSH_1P1T_6x3.5mm_H4.3_APEM_MJTP1243 | 3 | SW_Push

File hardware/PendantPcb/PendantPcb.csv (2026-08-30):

Comment | Designator | Footprint
SW_Push | SW3 | Button_Switch_SMD:SW_Push_1P1T_NO_E-Switch_TL3301NxxxxxG
SW_Push | SW2 | Button_Switch_SMD:SW_Push_1P1T_NO_E-Switch_TL3301NxxxxxG
SW_Push | SW1 | Button_Switch_SMD:SW_Push_1P1T_NO_E-Switch_TL3301NxxxxxG
Conn_01x04_Socket | J3 | Connector_PinHeader_2.54mm:PinHeader_1x04_P2.54mm_Horizontal
Conn_02x16_Odd_Even | J2 | Connector_PinHeader_2.54mm:PinHeader_2x16_P2.54mm_Vertical

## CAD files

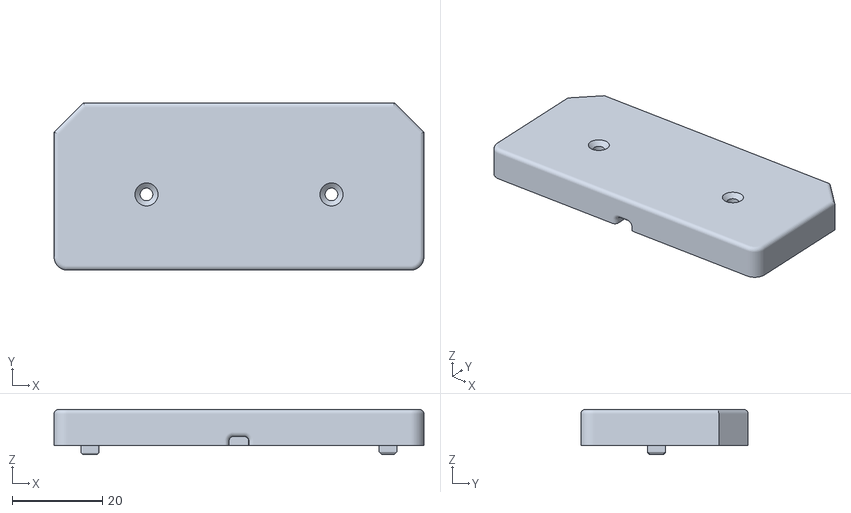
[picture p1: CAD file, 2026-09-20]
hardware/CADandSTL/Mount/MountBase.stl
82.0 x 37.1 x 10.0

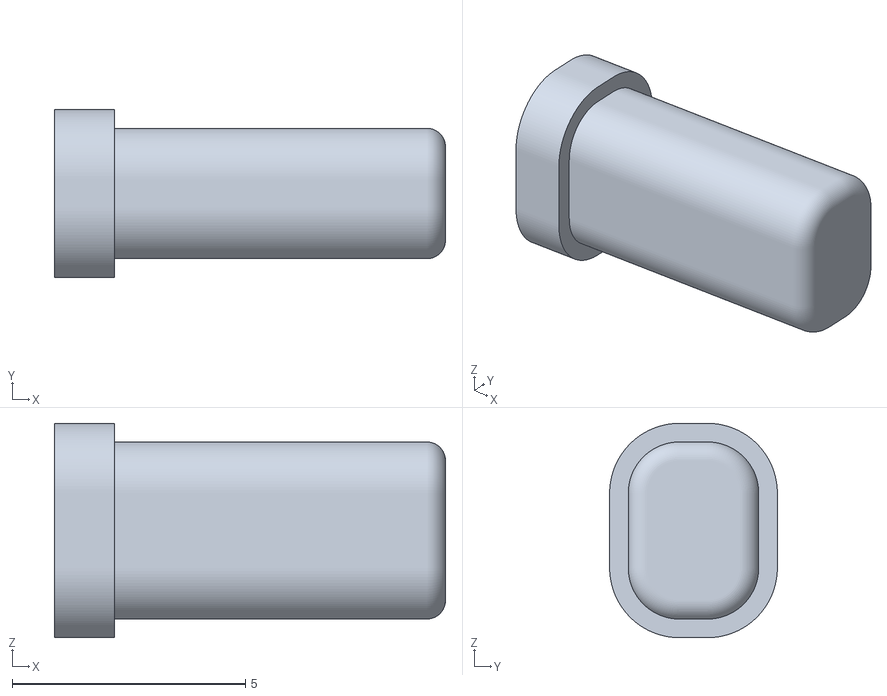
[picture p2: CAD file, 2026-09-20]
hardware/CADandSTL/Pendant/PowerButton.stl
8.39 x 3.60 x 4.60

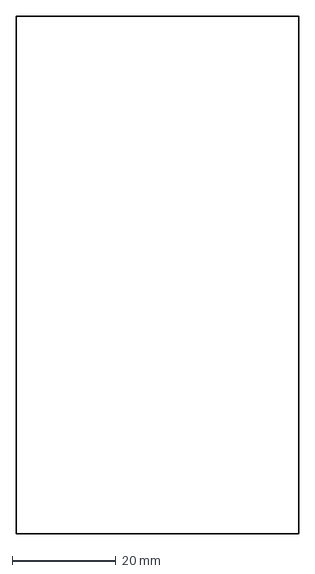
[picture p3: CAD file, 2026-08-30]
hardware/Outline.dxf
54.5 x 100.0 mm

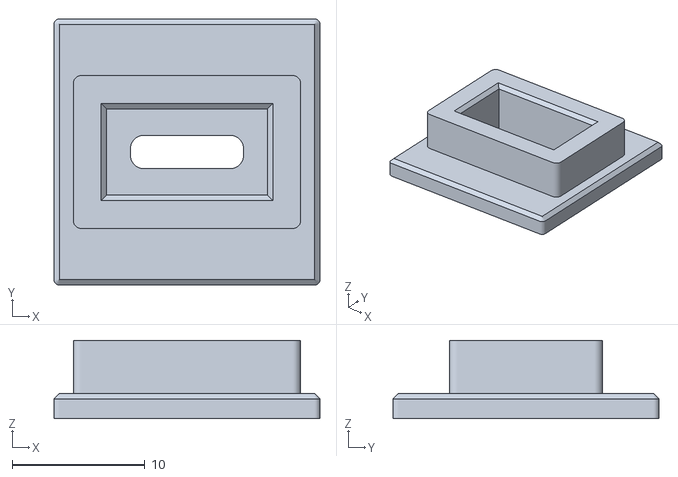
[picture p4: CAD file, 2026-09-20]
hardware/CADandSTL/Mount/MountUsb.stl
20.0 x 20.0 x 5.90

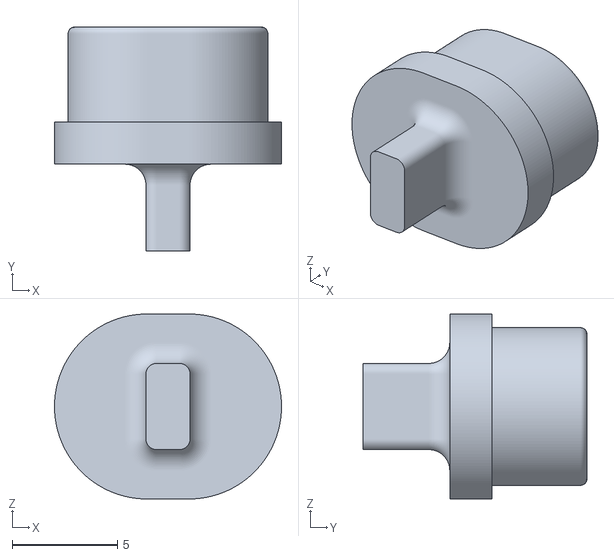
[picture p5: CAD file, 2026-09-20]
hardware/CADandSTL/Pendant/Button3.stl
10.8 x 10.6 x 8.80

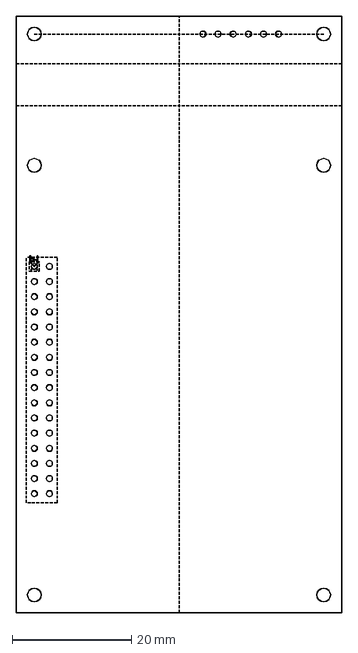
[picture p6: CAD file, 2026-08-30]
hardware/Holes.dxf
54.5 x 100.0 mm

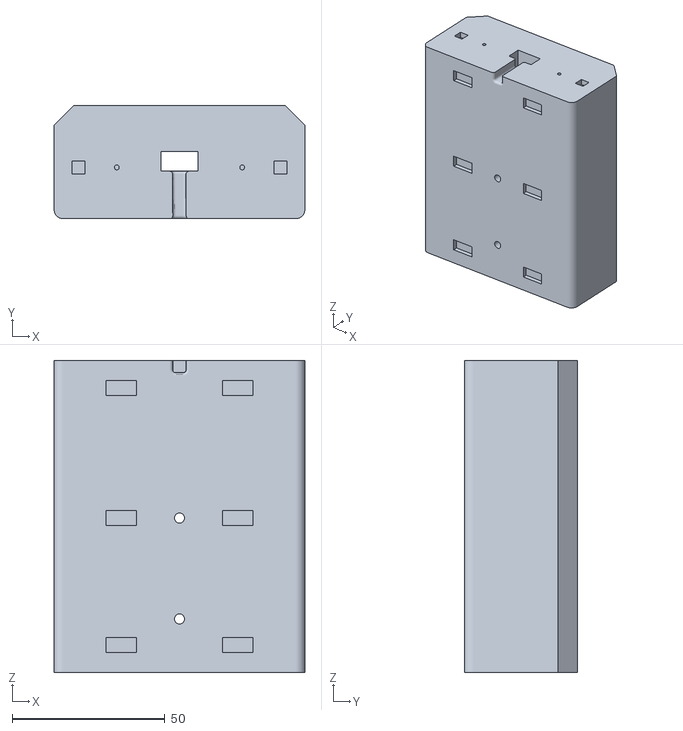
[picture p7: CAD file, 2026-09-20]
hardware/CADandSTL/Mount/Mount.stl
82.0 x 37.1 x 102.0

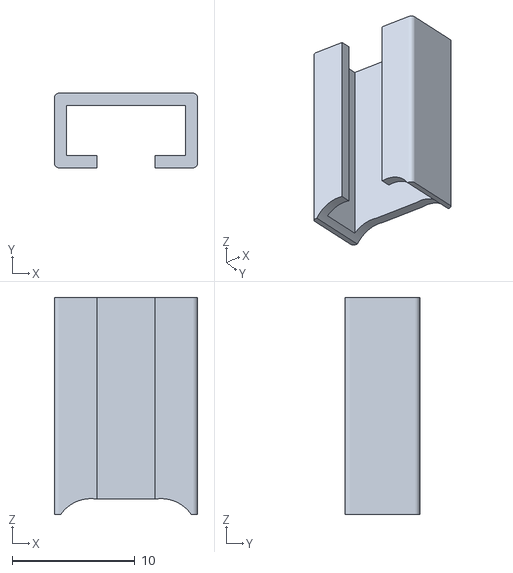
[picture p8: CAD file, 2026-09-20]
hardware/CADandSTL/Mount/MountUsbLock.stl
11.7 x 6.10 x 17.7

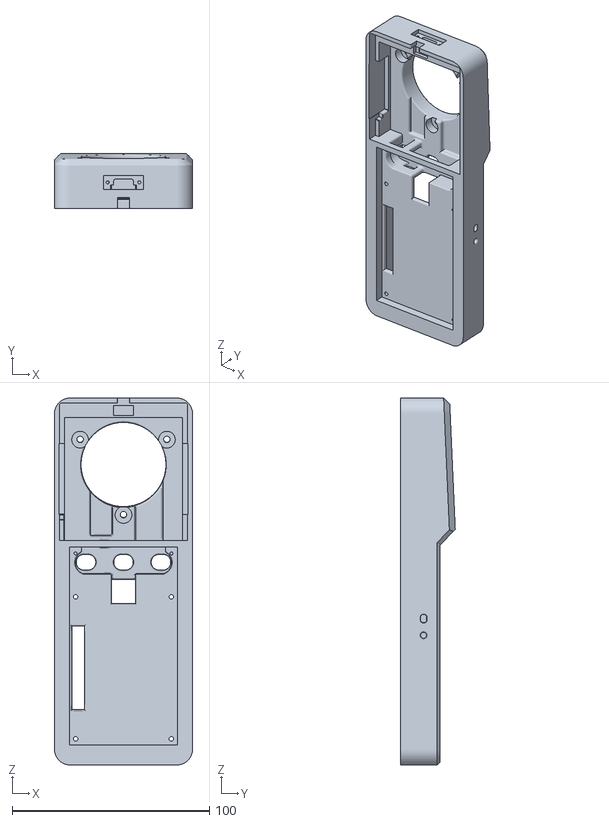
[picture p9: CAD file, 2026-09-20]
hardware/CADandSTL/Pendant/Pendant.stl
70.0 x 27.7 x 186.0

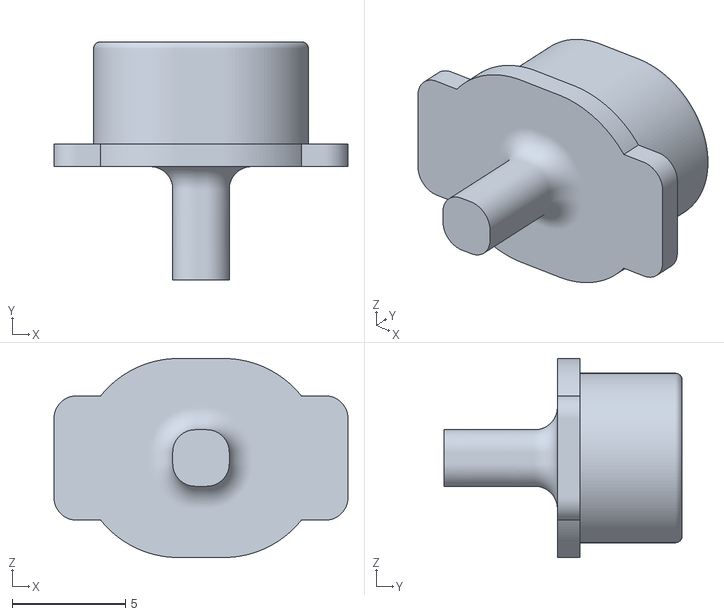
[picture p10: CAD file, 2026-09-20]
hardware/CADandSTL/Pendant/ButtonUsbV2.stl
13.0 x 10.5 x 8.80

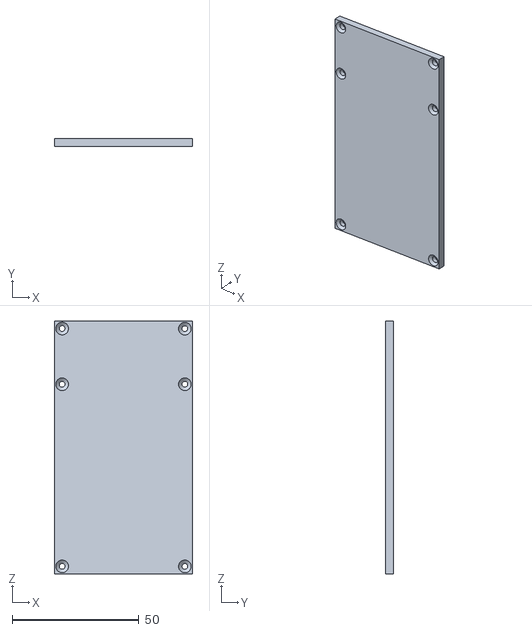
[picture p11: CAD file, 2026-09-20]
hardware/CADandSTL/Pendant/PcbCover.stl
54.7 x 3.16 x 100.0

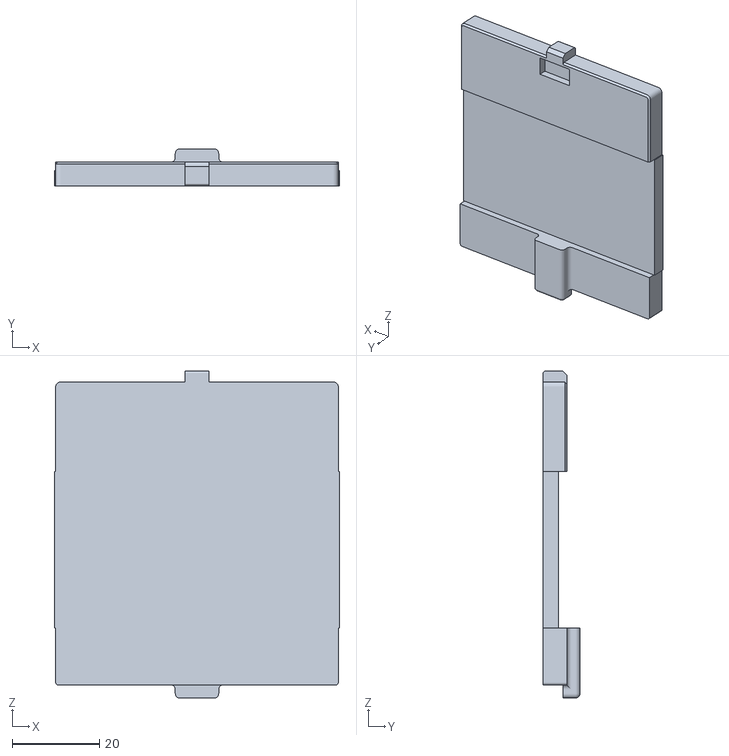
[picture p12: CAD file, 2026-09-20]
hardware/CADandSTL/Pendant/BatteryCover.stl
65.6 x 8.50 x 75.2

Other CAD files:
hardware/CADandSTL/Pendant/Button1.stl
hardware/CADandSTL/Mount/Mount.f3d
hardware/CADandSTL/Pendant/Pendant.f3d

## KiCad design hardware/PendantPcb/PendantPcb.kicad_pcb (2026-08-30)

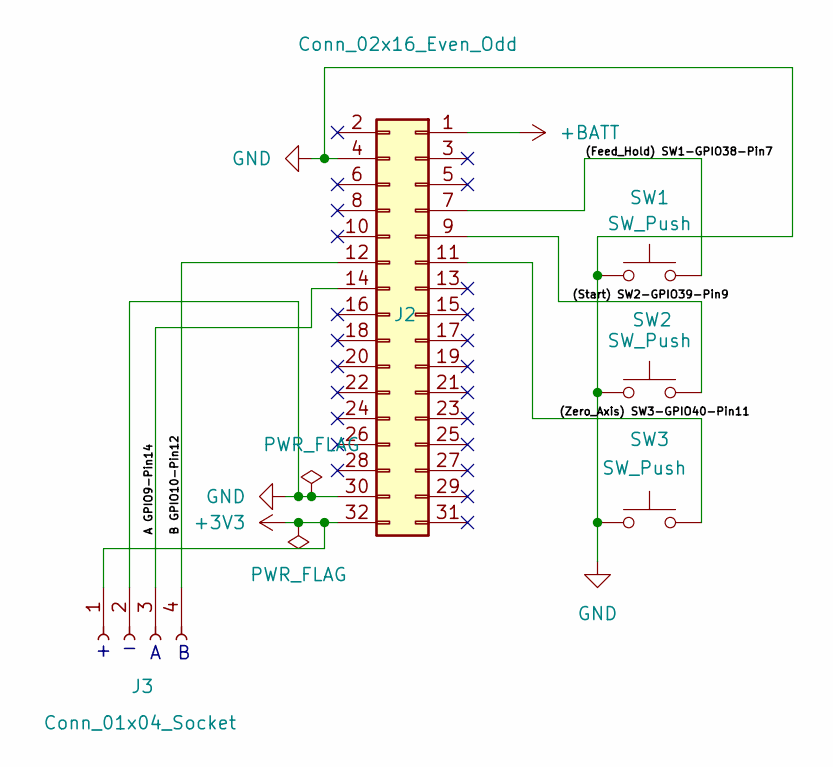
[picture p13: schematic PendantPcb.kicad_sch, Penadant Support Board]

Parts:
J2: Conn_02x16_Even_Odd; PinHeader_2x16_P2.54mm_Vertical_Left
J3: Conn_01x04_Socket; PinHeader_1x04_P2.54mm_Horizontal
SW1, SW2, SW3: SW_Push; SW_PUSH_1P1T_6x3.5mm_H4.3_APEM_MJTP1243

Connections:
+3V3: J2.32, J3.1
+BATT: J2.1
/(Feed_Hold) SW1-GPIO38-Pin7: J2.7, SW1.1
/(Start) SW2-GPIO39-Pin9: J2.9, SW2.1
/(Zero_Axis) SW3-GPIO40-Pin11: J2.11, SW3.1
/A GPIO9-Pin14: J2.14, J3.3
/B GPIO10-Pin12: J2.12, J3.4
GND: J2.4, J2.30, J3.2, SW1.2, SW2.2, SW3.2

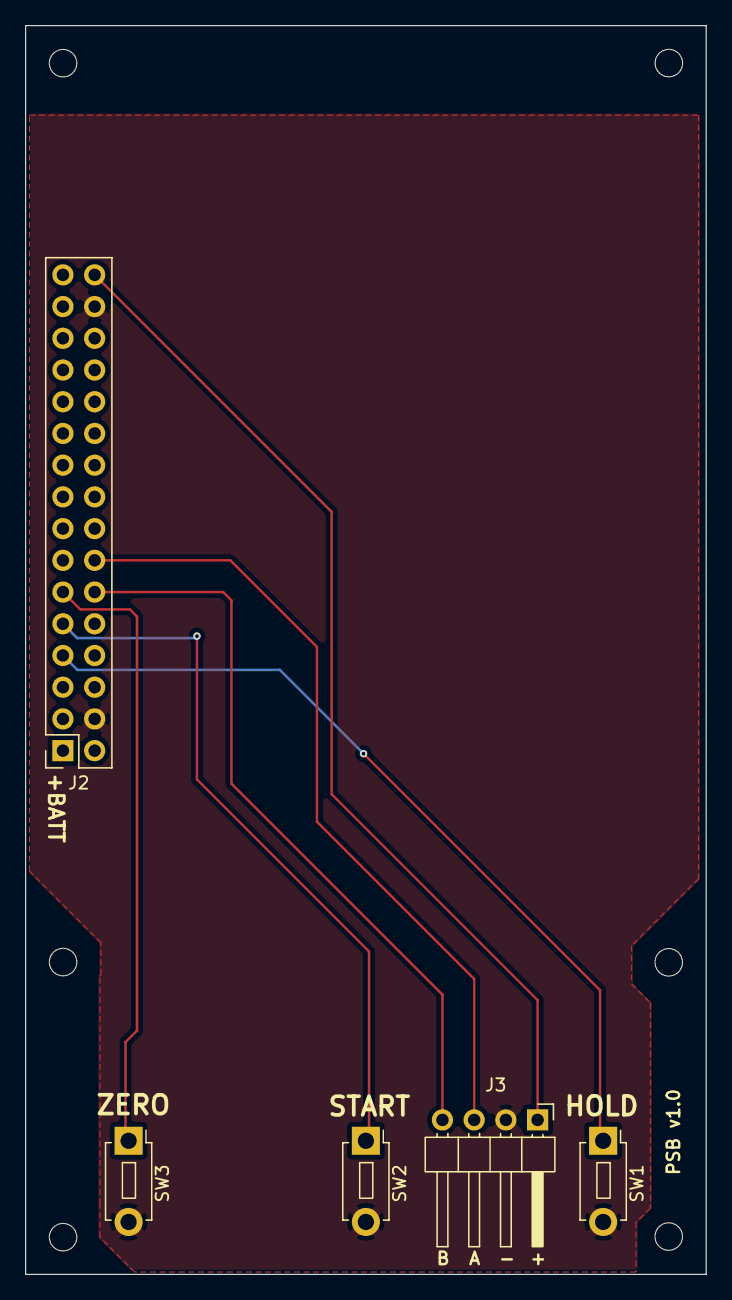
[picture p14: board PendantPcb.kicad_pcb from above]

Board: 2 copper layers, 54.5 x 100.0 mm, 5 parts (0 on the bottom side), 7 nets.

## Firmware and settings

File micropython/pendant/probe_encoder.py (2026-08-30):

"""Measure what the encoder actually puts out, using the ADC as a scope.

A multimeter cannot answer this. One detent of a 100 PPR wheel is one full
quadrature cycle, so both channels return to their resting state at every
click - catching the high level means holding the wheel between detents, and a
DVM on a moving signal reads the average rather than either level. Sampling
fast and reporting the two clusters gives the real answer.

**On the ESP32-S3 there is nothing to wire.** GPIO1-10 are all ADC1 channels,
so the encoder's own pins - GP9 and GP10 - are read in place.

On the Pico, GP2/GP3 are not ADC capable, so the DIVIDER OUTPUTS (the
junctions, not the encoder pins) have to be jumpered across:

    channel A junction  ->  GP26
    channel B junction  ->  GP27

That is safe by construction: a 10k/20k divider on a 4.9 V supply cannot
exceed 3.27 V, well inside the ADC's range. Do not connect the encoder pins
directly there - that is the thing we are trying to find out about.

**Set SUPPLY_V to whatever the encoder is actually running from**, and mind the
order when changing it. A 5 V encoder with the 22k removed puts 5 V on a pin
that is not 5 V tolerant, on either board. Move the supply to 3V3 first, then
take the resistors out.

Run it, then turn the handwheel steadily for the whole sampling window:

    python tools/on_board.py micropython/pendant/probe_encoder.py
"""

import time
import sys
from machine import ADC, Pin

_ESP32 = sys.platform == "esp32"

SAMPLE_SECONDS = 6
ADC_FULL_SCALE = 65535
ADC_VREF = 3.3

# The divider that is physically installed, so the tool can report the encoder
# side of it rather than just its own input.
#
# For an open-collector encoder the internal pull-up is already the top leg, so
# the external circuit is a single resistor to ground and R_TOP_K is 0 - the
# ADC then reads the encoder output directly and the ratio is 1.
#
#   characterising an unknown encoder:  10.0 / 20.0   (external divider)
#   verifying the open-collector fix:    0.0 / 22.0   (single resistor)
#   the 3V3 trial:                        0.0 /  0.0   (nothing external)
#
# Both zero means no external network at all - the ADC is on the encoder's
# output and the ratio is 1. Spelled out rather than left as 0/22, which gives
# the same ratio arithmetically while printing a resistor that is not on the
# bench.
R_TOP_K = 0.0
R_BOTTOM_K = 0.0

# On the ESP32-S3 the encoder's own pins are ADC channels - GPIO1-10 are all
# ADC1 - so there is nothing to wire. On the Pico, GP2/GP3 are not ADC capable
# and the divider junctions have to be jumpered across to GP26/GP27, which is
# what the header above describes.
CHANNELS = (("A", 9), ("B", 10)) if _ESP32 else (("A", 26), ("B", 27))

# What the encoder is actually being powered from, measured rather than
# assumed. Every conclusion below is relative to it: the same 3.06 V at the pin
# means "healthy open-collector" on a 5 V supply and "barely switching" on a
# 3.3 V one, so a stale value here inverts the answer rather than blurring it.
#
#   the shipped build:      4.909  (5 V rail, 22k to ground fitted)
#   the 3V3 trial:          3.3    (encoder on 3V3, 22k REMOVED)
SUPPLY_V = 3.3

# Input-high threshold of the part doing the reading. The ESP32-S3 wants
# 0.75 x VDD, appreciably higher than the RP2350's, and a level that was
# comfortable on the Pico can sit under it here.
INPUT_HIGH_V = 2.48 if _ESP32 else 2.15

# Levels are sorted into buckets and the two densest clusters reported. 40
# buckets over 3.3 V is ~82 mV of resolution, fine enough to separate a logic
# low from a logic high and coarse enough that noise does not fragment them.
BUCKETS = 40


def divider_ratio():
    total = R_TOP_K + R_BOTTOM_K
    if not total:
        return 1.0
    return R_BOTTOM_K / total


def sample(adcs, seconds):
    """Sample every channel as fast as the interpreter allows."""
    histograms = [[0] * BUCKETS for _ in adcs]
    extremes = [[ADC_FULL_SCALE, 0] for _ in adcs]
    count = 0

    deadline = time.ticks_add(time.ticks_ms(), seconds * 1000)
    while time.ticks_diff(deadline, time.ticks_ms()) > 0:
        for index, adc in enumerate(adcs):
            raw = adc.read_u16()
            bucket = raw * BUCKETS // (ADC_FULL_SCALE + 1)
            histograms[index][bucket] += 1
            if raw < extremes[index][0]:
                extremes[index][0] = raw
            if raw > extremes[index][1]:
                extremes[index][1] = raw
        count += 1

    return histograms, extremes, count


def volts(raw):
    return raw * ADC_VREF / ADC_FULL_SCALE


def bucket_volts(bucket):
    return (bucket + 0.5) * ADC_VREF / BUCKETS


def report(name, histogram, extremes, total):
    low_raw, high_raw = extremes
    print("\n  channel {}".format(name))
    print("    min {:.3f} V     max {:.3f} V".format(
        volts(low_raw), volts(high_raw)))

    # Split at the midpoint and take the densest bucket on each side. A clean
    # digital signal puts nearly all its time at two levels; anything else
    # means the signal is not switching cleanly.
    midpoint = BUCKETS // 2
    low_side = histogram[:midpoint]
    high_side = histogram[midpoint:]

    low_count = sum(low_side)
    high_count = sum(high_side)
    if not low_count or not high_count:
        print("    only one level seen - was the wheel turning?")
        return None

    low_peak = low_side.index(max(low_side))
    high_peak = midpoint + high_side.index(max(high_side))

    v_low = bucket_volts(low_peak)
    v_high = bucket_volts(high_peak)
    duty = 100 * high_count / total

    print("    resting low  ~{:.2f} V   ({:.0f}% of samples)".format(
        v_low, 100 * low_count / total))
    print("    driven high  ~{:.2f} V   ({:.0f}% of samples)".format(
        v_high, duty))
    print("    implied encoder output: {:.2f} V".format(
        v_high / divider_ratio()))

    # The top bucket is open-ended: everything from its lower edge to the ADC's
    # ceiling lands in it, and anything above the ceiling lands in it too. So a
    # high level reported there is a lower bound, not a measurement, and every
    # figure derived from it - the fraction of supply, the implied pull-up - is
    # derived from a number the ADC could not actually see.
    #
    # This matters here specifically because the three wirings worth telling
    # apart (5 V through the divider, 3V3 direct, and 5 V direct, which is over
    # the part's absolute maximum) all land in this one bucket.
    saturated = high_peak >= BUCKETS - 1
    if saturated:
        print("    ^ TOP BUCKET: >= {:.2f} V, upper edge unknown."
              .format(bucket_volts(high_peak) - ADC_VREF / BUCKETS / 2))
        print("      The ADC cannot see above its own ceiling, so this is a")
        print("      floor rather than a reading.")

    return v_high, saturated, duty
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

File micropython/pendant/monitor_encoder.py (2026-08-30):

"""Live readout from the handwheel. First check against real hardware.

Prints position, direction and rate as you turn, so you can confirm the wiring
end to end: that both channels are connected, that clockwise counts up, and
that one physical click produces exactly one detent.

Wire the divider junctions to GP2 (A) and GP3 (B), then:

    python tools/on_board.py micropython/pendant/monitor_encoder.py

Ctrl-C to stop. What to look for:

* One click of the wheel = one detent. If a click gives 2 or 4, the wheel is
  not 1 detent per quadrature cycle and COUNTS_PER_DETENT needs changing.
* errors stays at 0. A climbing count means electrical noise or a bad joint.
* Only one channel moving means the other is not connected - a single channel
  still produces edges, so a half-wired encoder looks alive but counts wrong.
"""

import sys
import time
from machine import Pin

# Same board split as pendant.py, and for the same reason: the RP2350 decoder
# uses a hard pin IRQ the ESP32 port does not have, and the ESP32 counts in
# PCNT hardware instead. A monitor pinned to one of them measures the wrong
# board silently - it simply reads nothing and looks like a wiring fault.
_ESP32 = sys.platform == "esp32"

if _ESP32:
    try:
        from quadrature_pcnt import Quadrature, COUNTS_PER_DETENT
    except ImportError:
        from pendant.quadrature_pcnt import Quadrature, COUNTS_PER_DETENT
    PIN_A, PIN_B = 9, 10
else:
    try:
        from quadrature import Quadrature, COUNTS_PER_DETENT
    except ImportError:
        from pendant.quadrature import Quadrature, COUNTS_PER_DETENT
    PIN_A, PIN_B = 2, 3

REFRESH_MS = 100

# Bounded rather than endless. Driven through `mpremote`, output does not reach
# the operator until the run finishes, so "Ctrl-C when you have seen enough"
# means seeing nothing until you guess it is time to stop. A fixed window turns
# it into: start it, turn the wheel until it ends, read the summary.
#
# Ctrl-C still works and still summarises, for anyone running it over a
# terminal where the live rows are visible.
MONITOR_SECONDS = 30


def main():
    print("\nhandwheel monitor")
    print("=" * 52)
    print("  reading A on GP{}, B on GP{}".format(PIN_A, PIN_B))

    encoder = Quadrature(PIN_A, PIN_B)
    pin_a = Pin(PIN_A, Pin.IN)
    pin_b = Pin(PIN_B, Pin.IN)

    print("  idle levels: A={} B={}  (both should be 0 or 1, not floating)".format(
        pin_a.value(), pin_b.value()))
    print("\n  turn the wheel for {} s - Ctrl-C stops early".format(
        MONITOR_SECONDS))
    print("  one click is 4 counts; a click landing across a sample boundary")
    print("  shows as two rows summing to 4 (1+3, 2+2), which is not an error\n")
    print("  {:>9} {:>9} {:>7} {:>8} {:>10} {:>6}".format(
        "detents", "counts", "d.count", "errors", "detents/s", "dir"))

    last_counts = 0
    last_time = time.ticks_ms()
    peak_rate = 0.0

    deadline = time.ticks_add(time.ticks_ms(), MONITOR_SECONDS * 1000)

    try:
        while time.ticks_diff(deadline, time.ticks_ms()) > 0:
            time.sleep_ms(REFRESH_MS)

            counts = encoder.counts
            now = time.ticks_ms()
            elapsed_ms = time.ticks_diff(now, last_time)
            delta = counts - last_counts
            last_counts, last_time = counts, now

            rate = 0.0
            if elapsed_ms > 0:
                rate = abs(delta) * 1000.0 / (COUNTS_PER_DETENT * elapsed_ms)
            if rate > peak_rate:
                peak_rate = rate

            if delta > 0:
                direction = "CW"
            elif delta < 0:
                direction = "CCW"
            else:
                direction = "-"

            print("  {:>9} {:>9} {:>+7} {:>8} {:>10.1f} {:>6}".format(
                encoder.detents, counts, delta, encoder.errors, rate,
                direction))

    except KeyboardInterrupt:
        pass
    finally:
        # Every figure read before deinit(), not after. `detents` and `counts`
        # both go through the PCNT hardware, so reading either from a decoder
        # that has been shut down gives a number that is wrong without looking
        # wrong - it reported -2500 against a table that ended at -4173.
        counts = encoder.counts
        detents = encoder.detents
        errors = encoder.errors
        encoder.deinit()

        print("\n  final: {} detents, {} counts, {} errors".format(
            detents, counts, errors))
        print("  peak rate: {:.1f} detents/s".format(peak_rate))
        print("  idle levels now: A={} B={}".format(
            pin_a.value(), pin_b.value()))

        if errors:
            print("  errors seen - check joints and that both channels are wired")
        elif _ESP32:
            # PCNT raises nothing of its own, so a zero error count on the
            # ESP32 means only that nothing was counting errors. The scale is
            # the check instead: leave the wheel resting in a detent and the
            # total must be a whole number of quadrature cycles. A remainder is
            # an edge that was missed or invented, which is exactly the symptom
            # an under-driven encoder would produce.
            # abs() first. Turning the wheel anticlockwise makes counts
            # negative, and Python's modulo of a negative number is the
            # non-negative complement - so 16695 counts CCW reported "1 left
            # over" where the wheel was really 3 counts into the next detent.
            # The sign is direction; it has nothing to do with the scale.
            magnitude = abs(counts)
            remainder = magnitude % COUNTS_PER_DETENT
            print("  {} counts is {} whole detents and {} counts over".format(
                counts, magnitude // COUNTS_PER_DETENT, remainder))
            if not remainder:
                print("  clean scale - every count formed a whole detent")
            else:
                # A remainder of one to three counts is where the wheel stopped,
                # not evidence of anything. It only means lost edges if the
                # wheel is genuinely detented and sitting in one, and a hand
                # leaving it mid-click is the ordinary case - so this says what
                # it saw rather than pronouncing on it.
                print("  {} of {} counts into the next detent. That is where".format(
                    remainder, COUNTS_PER_DETENT))
                print("  the wheel stopped unless it is resting hard in a")
                print("  detent, in which case it is a lost or invented edge.")
                print("  {} counts total, so this is {:.3f}% either way.".format(
                    magnitude, 100.0 * remainder / magnitude))
        else:
            print("  clean run, no illegal transitions")
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

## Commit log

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2026-08-07 feat: add MicroPython smoke test and board notes
    Six-stage bring-up check (identity, LED, temp sensor, WiFi scan, join,
    and end-to-end network IO) that reports pass/fail per stage. The WiFi
    stages skip cleanly when secrets.py is absent so the script is useful
    before credentials are chosen.
    README covers flashing, mpremote usage, and the three Pico 2 W specific
    gotchas: the LED living on the CYW43 rather than GPIO 25, GP29 being
    consumed by the WiFi SPI, and erratum RP2350-E9 on A2 silicon.
    [secrets.example.py, smoke_test.py]
2026-08-07 fix: use python -m mpremote and trim version string
    Bare `mpremote` is not on PATH under Microsoft Store Python, which installs
    console scripts to a sandboxed per-user directory the Store shim does not
    cover. Switch all documented invocations to the `-m` form, which works
    regardless, and document the optional user-scope PATH fix.
    Also call out that the placeholder SSID in secrets.example.py must be edited
    (it surfaces as a confusing "no such network in range"), add `mpremote devs`
    plus the 2e8a PID meanings for checking the board is seen, and slice
    sys.implementation.version to 3 fields so identity stops printing "1.28.0.".
    [secrets.example.py, smoke_test.py]
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2026-08-07 feat: quadrature decoder for MPG handwheel
    Full 4x decode on pin interrupts, both edges of both channels, with a 16-entry
    Gray-code transition table. Illegal transitions - the ones that skip a step and
    so can only mean a missed edge or contact bounce - are counted separately
    rather than guessed at, giving a wiring-quality signal.
    Interrupts rather than PIO on purpose: a hand-turned 60mm wheel peaks near
    2000 edges/s, two orders of magnitude inside what a hard IRQ handles. PIO is
    the right tool for a motor-mounted encoder, not one a human turns, and this
    state machine is far easier to verify. Registered hard=True so a slow SPI
    display refresh cannot delay it into missing edges; all mutable s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
    [quadrature.py, selftest_quadrature.py, test_quadrature.py]
2026-08-07 feat: pendant wire protocol with framing decoder
    Newline-delimited JSON over TCP. System.Text.Json reads it with no custom
    parser on the C# side, and a packet capture is readable without tooling. At
    tens of jog messages per second the encoding overhead is noise next to the
    network round trip.
    jog carries a signed detent count plus a step size rather than a target
    position, so a dropped message costs a little motion instead of leaving the
    two ends disagreeing about where the axis is. Step-size policy stays with the
    sender, which is the side that knows the machine.
    LineDecoder reassembles messages across arbitrary TCP chunk boundaries and
    caps the buffer, so a peer that never sends a newline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
    [protocol.py, test_protocol.py]
2026-08-07 fix: correct off-by-one in quadrature self-test harness
    The drive sequence began with the parked state (0,0). When the pins already
    rested there - which they do after any run that ends parked - that first write
    produced no edge, costing exactly one count and reading as a missed edge. It
    showed up as reverse returning -99 of -100 while forward returned 100, and as
    the slowest speed row missing while every faster row passed. Speed faults do
    not behave that way; the decoder was correct throughout, as the net-zero
    reversal test passing with zero errors already indicated.
    Drive sequences now start and end parked, so every write is a real transition
    regardless of history, and each test parks then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
    [selftest_quadrature.py]
2026-08-07 feat: pendant network link and mock sender
    link.py joins WiFi and holds a self-healing TCP session to the sender. The
    pendant is the client because the sender is the fixed always-on end.
    Beyond a plain socket it handles three things. A ping every 3s plus a 10s
    receive deadline catches a peer that vanished without closing - otherwise the
    session lingers for minutes and presents as a handwheel that has just stopped
    working. The send queue is bounded and drops oldest, so a pendant that cannot
    reach the sender never accumulates stale jog commands that all execute at once
    when the link returns. Nagle is off, as in the serial bridge.
    flush() exists because closing a socket discards whatever is s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
    [link.py, mock_sender.py, selftest_link.py]
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2026-08-07 fix: encoder is open-collector, not a line driver
    Measured on hardware: both channels rest at 0.12V and drive to 2.27V through a
    10k/20k divider, implying the encoder output reaches only 3.40V against a
    4.909V supply. A push-pull driver would not droop 1.5V at 120uA. Solving the
    divider backwards gives an internal pull-up of ~13.3k, and the model then
    reproduces the measurement exactly: 4.909 x 20/(13.25+10+20) = 2.27V.
    Six terminals - A, B, 0V, Vcc, A-, B- - was read as a differential line driver
    earlier. Open-collector with complementary outputs presents identically at the
    terminal block, and only measurement distinguishes them.
    The consequence is topological, not a matter of values: an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
    [probe_encoder.py]
2026-08-07 feat: live handwheel monitor for hardware bring-up
    Prints position, direction and rate while turning, to confirm the three things
    that go wrong on first wiring: that one physical click yields exactly one
    detent, that errors stay at zero, and that both channels are actually
    connected. The last matters because a single connected channel still generates
    edges, so a half-wired encoder looks alive while counting wrongly.
    Also reports idle pin levels at startup, which distinguishes a properly driven
    input from a floating one before any turning happens.
    Encoder measured at 3.26V through the corrected 22k-to-ground wiring, against
    a predicted 3.06V. Solving backwards puts the internal pull-up near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
    [monitor_encoder.py]
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2026-08-07 test: cover rest dither; clarify monitor output
    Hardware bring-up on the real handwheel confirmed one click is exactly 4
    counts and one detent, with zero illegal transitions across a full run - the
    decoder and the corrected open-collector wiring both check out.
    Two things in the output looked like faults and were not. Rates of 2.5 and 7.5
    detents/s were a click's 4 counts straddling the monitor's 100ms sample
    boundary, splitting 1+3 or 2+2 across two rows; the monitor now prints the
    per-sample count delta and says so, since the rate column alone invited exactly
    the wrong reading.
    The occasional single-count direction flip is a wheel resting on a quadrature
    edge and toggling one channel fro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
    [monitor_encoder.py, test_jog.py]
2026-08-07 feat: assemble the pendant
    Wires the decoder, jog scheduler and network link into one application and
    runs them as concurrent tasks. Each was built and tested on its own; this is
    the join.
    Reports periodically rather than staying silent, since a headless pendant with
    no display gives no other indication of whether it is connected, what axis and
    step are selected, or whether the encoder is accumulating errors. The LED
    follows link state and is written only on change, for the CYW43 SPI contention
    reason established in the serial bridge.
    No display or buttons required. Axis and step are set at the top and can be
    changed live from the REPL through the module-level scheduler object, which is
    en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
    [pendant.py]
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2026-08-07 change: halt on wheel stop; replace jog cancel button with zero axis
    Adopt velocity-follow semantics for the handwheel: stopping the wheel flushes
    queued motion and halts, rather than letting the machine run on through a
    backlog. The trade is exactness - ten fast clicks may travel less than ten
    steps' worth because the remainder is cancelled - which is the right trade for
    an input used to position by eye.
    That behaviour already existed, but at a 60ms threshold that was too eager to
    be safe. A slow turn of 3 detents/second leaves 200ms gaps, so it would have
    fired between individual detents and truncated jogs mid-move during ordinary
    slow jogging. Raised to 300ms, which someone winding conti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
    [jog.py, mock_sender.py, pendant.py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]
2026-08-07 feat: make jog cancel behaviour switchable at runtime
    Which of velocity-follow and queue-and-execute feels right is a question for a
    real machine, not an argument. Exposing it as a flag rather than a constant
    turns that comparison into a REPL line instead of an edit, copy and restart
    cycle:
    scheduler.cancel_on_stop = False
    Default is unchanged. Tests cover detents still arriving with cancel disabled,
    no cancel being emitted on stop, and flipping back mid-session restoring the
    original behaviour - the last mattering because the point of the flag is
    comparing both on one machine in one session.
    README records the trade and notes that step size may already cover the
    underlying need: coar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
    [jog.py, test_jog.py]
2026-08-07 feat: publish pendant mode; add board sync tool
    Axis and step never left the pendant, since they only change what future jog
    messages say. That made them invisible to the sender - and to anyone watching
    it, which is how they looked broken during testing while working correctly.
    The pendant now publishes a mode message on change, and again on reconnect,
    because a sender that has just reconnected has no memory of what the wheel is
    set to. The mock shows it alongside the DRO.
    tools/sync_board.py copies the runtime modules and secrets to the board,
    comparing hashes so repeat runs are cheap. Board files are independent copies
    rather than a view of the repo, and that has now caused two silent fai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
    [mock_sender.py, pendant.py, protocol.py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]
2026-08-07 fix: discard stale queue on reconnect; correct link state and backoff
    Three faults, all visible in one bring-up log where the sender was not
    listening.
    Messages queued while the link was down were replayed on reconnect. The log
    shows a minute of accumulated button presses - and a zero - arriving at once
    the moment the sender returned. Queued pendant input is operator intent, and
    intent expires: detents from a wheel that has since stopped, a button pressed
    a minute ago. The queue now starts each session empty and reports what it
    discarded.
    `connected` was set as soon as open_connection returned, but a TCP connect can
    return before the handshake completes, so a link about to be reset reporte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
    [link.py]
2026-08-07 feat: ILI9341 DRO display
    Minimal driver plus a DRO layout behind a small interface, so the panel choice
    stays a swap of one import rather than a rewrite - nothing above screen.py
    knows it is an ILI9341.
    Redraws per character and only where the character changed. A DRO is mostly
    static: two or three digits move per status frame and the rest do not.
    Measured on hardware that is 38 fps against the 10 needed, while a full-screen
    fill costs 130 ms - which is why the layout never does one after startup.
    Colours are stored byte-swapped because the panel wants big-endian while
    MicroPython's RGB565 framebuf is native little-endian. Pre-swapping lets a
    framebuf go straight down SPI with no per-pixe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
    [ili9341.py, pendant.py, screen.py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]
2026-08-07 change: axis labels to 24px
    Half the digit height read as an afterthought, which is wrong for the element
    you glance at to know which axis the wheel will move - especially since the
    selected one is highlighted and meant to be legible at arm's length.
    Nine digit cells at 32px is 288 of the panel's 320, so the label column is
    whatever remains. Moving the digits from x=32 to x=30 frees enough for a 24px
    glyph at x=4, leaving 2px either side. Labels now read at three quarters of
    the digit height instead of half, with the position readout untouched - it is
    the thing actually being read, so it keeps the space.
    [screen.py]
2026-08-07 feat: single command to sync and start the pendant
    The two-step version is easy to get wrong in both directions, and both have
    now happened. Skipping the sync silently runs stale modules on the board -
    which produced a button that appeared to do nothing, against a protocol.py
    predating the function it called. Skipping the run looks identical to a
    pendant that is broken, when it simply was never started.
    Doing them together removes the choice. Also record in the README that nothing
    auto-starts: there is deliberately no main.py, so the board always boots to a
    free REPL. Making pendant.py the boot script would hold the REPL from power-up,
    which wants an escape hatch first.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
    [run_pendant.py]
2026-08-07 feat: toggle jog mode from the pendant, and show which is active
    I claimed cancel_on_stop could be flipped from the REPL on a running pendant.
    It cannot: `mpremote run` holds the serial port for the whole session, so there
    is no second connection available to get a REPL. Comparing the two modes would
    have meant stopping the pendant, which defeats the point of comparing them.
    Holding the axis button now toggles it. That is where the comparison has to
    happen anyway - the modes differ only by feel, so the judgement is made
    standing at the machine, not at the PC.
    The display shows HALT or QUEUE alongside axis and step, because two modes
    that differ only in feel are exactly the case where guess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
    [pendant.py, protocol.py, screen.py]
2026-08-07 change: turn rate drives feed rate, not distance
    Distance scaling was the wrong answer and the operator caught it. Commanding
    several times more travel than the machine can execute while the wheel turns
    builds a queue, and then how far the axis actually moved depends on how deep
    that queue was when you stopped - it either runs on, or the cancel discards an
    unpredictable part of it. Either way the wheel stops meaning anything specific,
    which is the run-off risk.
    Distance is now always exactly one step per detent. Only the feed varies, set
    to the rate the operator is already commanding: detents/s x mm/detent x 60. The
    machine tracks the hand, each small move completes quickly so the queue sta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
    [jog.py, pendant.py, protocol.py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]
2026-08-08 tune: finer rate resolution, suspend 5mm step, raise ceiling to 5000
    Machine testing showed the feed staircasing rather than ramping, and the 5 mm
    step pinning at maximum almost immediately.
    The ramp problem was measurement granularity. Rate was counted in whole
    detents over the window, so the smallest detectable change was one detent per
    200 ms - 5 detents/s, which at the 1 mm step is a 300 mm/min jump. Rate is now
    accumulated in raw quadrature counts, four per detent, over a 300 ms window.
    That takes the feed granularity from 300 mm/min to 50 at 1 mm, and from 30 to
    5 at 0.1 mm. The longer window also softens the ramp itself, since feed rises
    and falls over its length.
    The 5 mm step is s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
    [jog.py]
2026-08-08 fix: bound in-flight motion; feed curve so fine steps reach usable rates
    Two faults found on the machine.
    Run-on grew the longer the pendant was used. Turning faster than the feed
    ceiling can execute banks the surplus, and back-and-forth jogging never pauses
    the 300ms needed to trigger a cancel, so the backlog accumulated monotonically
    across a session. The scheduler now tracks an estimate of motion in flight -
    adding what it commands, draining what the feed executes each tick - and drops
    anything beyond MAX_QUEUE_MM rather than queueing it. That constant is directly
    how far the machine can still travel after the wheel stops.
    Bounding accumulated distance rather than per-tick distance matt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
    [jog.py, test_jog.py]
2026-08-08 fix: feed must not exceed the commanded rate
    Fine steps were rough and violent on the machine while 1 mm was smooth, and the
    curve added last commit is why. Distance per detent is fixed, so a higher feed
    covers no more ground - it makes each move finish early and then wait. At 0.1 mm
    and 5000 mm/min a move lasts 1.2 ms of a 20 ms tick, so the planner accelerates
    hard and decelerates to a stop once per detent. The 1 mm step felt right only
    because its commanded rate happened to be near the ceiling already.
    Feed is now exactly rate x step x 60, so a message spans about one tick and
    consecutive jogs blend into continuous motion. terjeio's MPG firmware does the
    same - F straight from encoder ve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
    [jog.py, test_jog.py]
2026-08-08 fix: measure turn rate by interval; cap feed per step size
    The stutter and jerk as the wheel comes to rest was the windowed rate estimate.
    A window is wrong in both directions - too slow to rise, so a fast start
    out-runs the feed and fills the queue, and too slow to fall, so winding down
    leaves the feed high while detents arrive ever further apart. Every move then
    finishes early and waits, which is what is felt as the wheel stops. The fast
    attack added last commit fixed the rise and left the fall untouched.
    Rate is now detents divided by the interval they actually took, which is
    accurate at any speed and reacts within a single detent either way. terjeio's
    firmware gets the same measurement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
    [jog.py, test_jog.py]
2026-08-08 tune: smooth the feed, add a 0.5mm step
    Two findings from the machine.
    The 1 mm step felt dead for several revolutions before moving. That is the
    queue bound doing its job on a step that is too coarse for the operator's
    turning speed: at ~300 detents/s, 1 mm asks for 18000 mm/min, the machine
    delivers 5000, and the rest is necessarily dropped - so the wheel moves the
    axis far less than the hand suggests. The step that maps a natural turn onto
    maximum feed is feed_max / (60 x detents_per_second), around 0.28 mm here, so
    0.5 mm is added to fill the gap between 0.1 and 1.0.
    Roughness that persisted after the wind-down fix was rate variance, which the
    operator identified: interval measurement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
    [jog.py, test_jog.py]
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2026-08-08 fix: feed ordering at motion start; per-axis and coarse ceilings
    _moving was set before feed_rate ran, so every start looked like a
    continuation and the feed smoothed up from the floor instead of jumping to
    target - 275 mm/min where 950 was called for. Since the queue bound derives
    from the feed, that also discarded five of the first seven detents at exactly
    the moment the operator began turning, which is the coarse-step dead zone.
    Feed is now computed before _moving is set.
    Machine limits are now real rather than guessed: X and Y do 15000 mm/min and Z
    6000, so the ceiling follows the axis. Commanding a feed an axis cannot reach
    only runs it at full acceleration.
    Coarse step ceilings raise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
    [jog.py, test_jog.py]
2026-08-08 tune: coarse ceilings to the machine's real limit
    Reported keeping ~60% at the 1 mm step. Working backwards, that is a wind of
    roughly 330-400 detents/s - 3 to 4 revolutions a second - which at 1 mm demands
    20000 to 24000 mm/min. X and Y top out at 15000, so a third of it cannot be
    delivered by anything.
    Coarse ceilings raised to 12000 and 15000 so nothing is discarded that the
    machine could actually have executed. At that wind, 0.5 mm demands 12000 and
    survives in full, while 1 mm is only fully usable below about 250 detents/s.
    That makes 0.5 mm the traverse step for a hand that turns this fast; it is a
    property of the wheel and the machine rather than something a ceiling can fix.
    Co-Auth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
    [jog.py]
2026-08-08 fix: hold the feed steady, so the planner can blend
    Jerking once up to speed was the feed changing on every message. grblHAL blends
    consecutive moves that share a feed rate; one that drifts continuously forces a
    velocity change between every block - accelerate, decelerate, accelerate. The
    diagnosis came from the machine: clamping the feed to a constant 1200 was
    smooth, and raising the clamp so the pendant's own value got through brought the
    jerking back.
    Adjusting FEED_SMOOTHING made little difference, which fits - smoothing changes
    how fast the feed moves, not how often. Over 200 messages from a steady hand it
    still produced 200 different values.
    The feed now holds unless the target leave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
    [jog.py, test_jog.py]
2026-08-08 fix: make feed hysteresis asymmetric
    Reported that after a stumble the feed stopped matching the hand and stayed
    rough, most noticeably at 0.5 mm where the demand sits nearest the ceiling.
    The band added last commit was symmetric, so after any slowdown the feed could
    sit up to 20% above what the hand was now asking. A feed above the commanded
    rate means every move finishes early and waits, which is the stutter - and it
    is self-sustaining, because the target has to fall a further 20% before the
    feed is allowed to follow.
    The two directions are not equally harmful. Too high stalls between blocks and
    persists; too low is absorbed by the queue bound dropping, which is unpleasant
    but self-limit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
    [jog.py, test_jog.py]
2026-08-08 fix: feed could never reach its target
    Reported that after lowering the ceilings the feed topped out below them, and
    that any variation then brought the jerking back. That is a real fault and the
    diagnosis was right: it was topping out at a threshold rather than at the cap.
    Easing towards the target while a deadband suppresses small changes cannot
    converge. Each step covers a quarter of the remaining gap, so the gap shrinks
    until it fits inside the band - and there it stops, permanently short. With a
    20% band the feed stalled around 17% below whatever it was climbing towards.
    Under-feeding is the harmful direction. Distance then arrives faster than it
    drains, the queue grows, the bound beg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
    [jog.py, test_jog.py]
2026-08-08 fix: stop cancelling when the operator re-grips the wheel
    Reported a dead stop, a pause, then a ramp back up - about three times across a
    49 inch traverse, and twice as often at 0.5 mm as at 1 mm.
    That ratio is the whole diagnosis. The traverse needs 12 revolutions at 1 mm
    and 25 at 0.5 mm, which cannot be turned without letting go of the wheel, and
    every pause past IDLE_MS_BEFORE_CANCEL flushed the queue and stopped the
    machine dead. Twice the revolutions, twice the re-grips, twice the stops.
    Threshold raised from 600 ms to 2.5 s. What makes that safe is that the cancel
    is now nearly redundant: in-flight motion is bounded to a few ticks, so letting
    go of the wheel stops the machine within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
    [jog.py, test_jog.py]
2026-08-08 change: larger messages and a small planner buffer
    Machine reports the pendant's commanded feed sitting perfectly still at 9000
    while grblHAL's actual feed oscillates and the axis jerks continuously through
    a long move. The commanded feed is not the problem; the planner is running dry.
    Two things starve it.
    A tick carries a whole number of detents, so at 20 ms and a fast wind a single
    detent is 17% of the message. Tick raised to 50 ms, where the same detent is 7%
    of a message three times the size. The latency cost is nil in practice - the
    sender dispatches its own jogs every 75 ms, so this was never the limiting
    quantiser.
    And commanding exactly the arrival rate leaves the queue hovering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
    [jog.py, test_jog.py]
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
